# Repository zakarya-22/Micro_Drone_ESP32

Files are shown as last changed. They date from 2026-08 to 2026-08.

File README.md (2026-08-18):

# 🚁 DIY ESP32-C3 Micro-Drone

## 1. Introduction et Objectif du Projet
L'objectif de ce projet est la conception de A à Z d'un mini-drone quadricoptère basé sur le microcontrôleur ESP32-C3. Ce projet multidisciplinaire couvre le prototypage mécanique, la conception électronique et le développement logiciel embarqué. Il implique le contrôle PWM de 4 moteurs à courant continu via des MOSFETs, la lecture de capteurs d'attitude (IMU) via I2C, et la gestion d'une alimentation par batterie LiPo.

## 2. 🛠️ Architecture Matérielle (Hardware)

* **Microcontrôleur :** ESP32-C3 Super Mini (Wi-Fi/Bluetooth, monocœur RISC-V).
* **Actionneurs :** 4 x Moteurs à courant continu (Coreless) avec hélices profilées.
* **Électronique de puissance :** Transistors MOSFETs pour la commutation des moteurs.
* **Capteur :** IMU (Inertial Measurement Unit) communicant en I2C pour la lecture de l'assiette du drone.
* **Alimentation :** Batterie LiPo Tattu 300mAh (avec alimentation de laboratoire utilisée pour les phases de test).
* **Mécanique :** Châssis conçu sur-mesure via **FreeCAD** et imprimé en 3D.
* **Circuit imprimé :** Routage réalisé sur **KiCad** et usinage d'un PCB personnalisé à l'aide d'une fraiseuse LPKF.

## 3. 💻 Architecture Logicielle (Software)
* **Environnement de développement :** Arduino IDE.
* **Modularité :** Le code est actuellement développé en modules séparés pour isoler et valider chaque sous-système de manière unitaire :
  * Un module dédié à l'acquisition des données de l'IMU via le bus I2C.
  * Un module dédié à la génération des signaux PWM (via `ledcWrite`) pour le contrôle de la vitesse des moteurs.

## 4. 🐛 Historique de Débogage et Résolution des Problèmes

Au cours du développement, plusieurs défis techniques ont été rencontrés et résolus méthodiquement :

### Défi 1 : Blocage de l'ESP32-C3 au démarrage (Erreur ESP-ROM)
* **Symptôme :** Après le téléversement du code, la carte refusait de lancer le programme et affichait uniquement le message `ESP-ROM` sur le port série.
* **Diagnostic :** La broche GPIO 9 (broche de "Strapping" définissant le mode de démarrage) mesurait une tension flottante de 0.2V au lieu d'un état haut (3.3V), forçant l'entrée en mode flash (*Download Mode*).
* **Solution :** Un reset électrique complet (décharge des condensateurs en court-circuitant 3V3 et GND hors tension) a purgé les charges résiduelles, validant la nécessité d'états électriques stables sur les broches de strapping.

### Défi 2 : Redémarrages intempestifs en charge (Brownout detector was triggered)
* **Symptôme :** Dès l'activation des moteurs, l'ESP32 plantait avec l'erreur `Brownout`.
* **Diagnostic :** L'appel de courant brutal des moteurs faisait chuter la tension d'alimentation sous le seuil critique (environ 2.8V).
* **Solution temporaire :** Passage sur une alimentation de laboratoire (3.65V - 4A) pour garantir la puissance nécessaire.

### Défi 3 : Problème de poussée inversée (Le drone "frappe" le sol)
* **Symptôme :** Les moteurs tournaient, mais le flux d'air plaquait le drone au sol au lieu de le soulever.
* **Diagnostic :** Sens de rotation incorrect et profil aérodynamique des hélices non respecté. Les MOSFETs unidirectionnels ne permettent pas de changer le sens logiciellement.
* **Solution :** Retournement physique des hélices (face bombée vers le haut) et inversion du câblage matériel des moteurs sur le PCB.

### Défi 4 : Comportement aléatoire des moteurs au démarrage
* **Symptôme :** Activation erratique des moteurs lors de la mise sous tension.
* **Diagnostic :** Les grilles (Gates) des MOSFETs captaient des signaux parasites à cause de la haute impédance (état flottant) des GPIOs pendant la séquence de boot de l'ESP32.
* **Solution :** Ajout de résistances de pull-down (10kΩ) entre les grilles et la masse (GND) pour forcer l'état bas tant que le PWM n'est pas envoyé logiciellement.

### Défi 5 : Capteur IMU non détecté sur le bus I2C
* **Symptôme :** Échec du scanner I2C, chute de la tension 3.3V du capteur.
* **Diagnostic :** Court-circuit ou inversion de polarité (VCC / GND) mettant l'alimentation en sécurité et bloquant le bus.
* **Action :** Isolement immédiat du circuit et inspection du câblage pour prévenir la destruction des composants.

## 5. 🚧 Problèmes Actuels et Améliorations Matérielles

Actuellement, les sous-systèmes fonctionnent parfaitement de manière isolée. Cependant, lors de la combinaison des codes, le microcontrôleur n'arrive pas à gérer les moteurs de façon stable (perte de puissance ou redémarrage). Voici les deux pistes de résolutions matérielles prioritaires en cours :

1. **Le seuil de commutation des MOSFETs (Logic-Level) :** L'ESP32-C3 fonctionne en logique 3.3V. Si les MOSFETs utilisés nécessitent une tension de grille de 5V ou plus pour saturer complètement (s'ouvrir à 100%), ils fonctionnent en régime ohmique (comme une résistance). Ils brident alors le courant destiné aux moteurs et dissipent de la chaleur. L'amélioration consistera à s'assurer d'utiliser des MOSFETs "Logic-Level" (ex: SI2302) ayant une très faible tension de seuil de grille ($V_{GS(th)}$).
2. **Filtrage et découplage de puissance (Brownout matériel) :** Pour absorber le gigantesque pic de courant généré au démarrage par 4 moteurs *coreless* et protéger l'ESP32 des chutes de tension, l'ajout d'un condensateur de forte valeur (ex: 470µF) au plus près de la ligne d'alimentation générale, combiné à des condensateurs de découplage proches de l'ESP32, est nécessaire.

## 6. 🚀 État Actuel et Prochaines Étapes
- [x] Modélisation du châssis sur FreeCAD.
- [x] Routage et usinage du PCB sur KiCad/LPKF.
- [x] Validation unitaire du code de l'IMU.
- [x] Validation unitaire du code PWM pour les moteurs.
- [ ] Résolution du problème d'alimentation/contrôle moteur avec l'ESP32 (Code combiné).
- [ ] Fusion propre du code dans un `flight_controller` unifié.
- [ ] Remplacement de l'alimentation de labo par la batterie Tattu 300mAh.
- [ ] Implémentation et réglage de la boucle d'asservissement PID.

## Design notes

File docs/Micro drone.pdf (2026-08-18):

🚁 Liste du matériel : Le Micro-Drone (Cible : ~55g)
Pour le cerveau du drone, je te conseille de prendre une version "Mini" de l'ESP32 pour gratter de précieux grammes.
Composant | Spécificités exactes (Mots-clés AliExpress) | Poids approx. | Prix estimé (€)
Microcontrôleur | ESP32 D1 Mini mais après brûlure esp32 super mini | 5 g | 4.00
Capteur IMU | MPU6050 Module (Gyroscope 3 axes + Accéléromètre) | 2 g | À l’école
Capteur Altitude | VL53L0X Time of flight sensor (Capteur laser) | 1.5 g | 3.00
Moteurs (x4) | Brushed 716 | 20 g (5g x4) | 6.00
Hélices (x8) | 55mm Propellers for the motors | 2 g | 2.00
MOSFETs (x10) | AO3400 | < 1 g | À l’école
Diodes & Résis. | Diodes SS14 (SMD) + Résistances 10k Ohms SMD (0805 ou 1206) | < 1 g | À l’école

Batterie 1S | 3.7V 300mAh Tattu battery JST/PH2.0 | 15 g | 10.00 (lot)
Structure | Châssis imprimé en 3D à l’école | ~10 g | 0.00 (École)
TOTAL | Objectif : Vol dynamique et autonomie de 4-6 minutes | ~56.5 g | ~29.50 €

🎮 Liste du matériel : La Manette de contrôle (Télécommande)

Composant | Spécificités exactes (Mots-clés AliExpress) | Prix estimé (€)
Microcontrôleur | ESP32 NodeMCU 38 pins (Classique, facile à brancher) | 5.00
Joysticks (x2) | Dual Axis XY Joystick Module (KY-023) | 2.50

Pour la manette, le poids n'a pas d'importance. L'utilisation d'un second ESP32 est l'option la plus intelligente : cela te permet d'utiliser le protocole ESP-NOW (un protocole Wi-Fi direct créé par Espressif, ultra-rapide, sans routeur, avec une latence quasi nulle).

📅 Plan de travail et Méthodologie

Ce projet demande de la rigueur. Si tu assembles tout en espérant que ça vole du premier coup, tu risques de casser tes composants. Voici la marche à suivre par étapes :

Phase 1 : Électronique et Motorisation (Test sur table)

1. Soude un seul moteur avec son MOSFET, sa diode et sa résistance sur un petit bout de plaque d'essai.
2. Écris un code très simple sur l'ESP32 pour faire varier la vitesse de ce moteur (PWM) de 0 à 100%.
3. Objectif : Valider ton circuit de puissance avant de le multiplier par 4.

Phase 2 : Communication (ESP-NOW)

1. Câble tes joysticks sur l'ESP32 de la manette.
2. Écris le code pour lire les valeurs des joysticks et les envoyer via ESP-NOW à l'ESP32 du drone.
3. Fais afficher ces valeurs sur le moniteur série de l'ordinateur connecté au drone pour vérifier que la transmission est instantanée et sans perte.

Phase 3 : Lecture de l'IMU et Programmation du PID (Le cœur du projet)

1. Branche le MPU6050 sur le drone (bus I2C).
2. Applique un filtre (Filtre Complémentaire ou Madgwick) pour obtenir les angles d'inclinaison (Pitch, Roll, Yaw) propres, malgré les vibrations.
3. Implémente la boucle PID (Proportionnelle, Intégrale, Dérivée). C'est l'algorithme qui dit : "Si je penche à gauche, j'accélère les moteurs gauches pour revenir à plat".

Phase 4 : Tests en "Tethered" (Vol captif)

1. Imprime ton châssis 3D et assemble tout le drone.
2. Fixe le drone à un système de balancier (une tige traversant le drone) ou attache-le par le dessus avec un fil mou.
3. Règle les valeurs de ton PID jusqu'à ce que le drone se stabilise tout seul sans s'emballer.

4. Dernière étape : Intègre le capteur VL53L0X pour gérer le maintien de l'altitude.

📍 Phase 1 : L'Inventaire et le Schéma Électrique (Eeschema)

Le but : Dire à KiCad "qui est connecté à quoi" avec les vrais composants.

1. Placement des Symboles : Nous allons chercher et placer les symboles de l'ESP32, de l'IMU, des 4 MOSFETs (A3400), des 4 Diodes (1N5819), des 8 Résistances, des Condensateurs et de la prise Batterie.
2. Câblage Virtuel : Nous allons tracer les fils verts pour relier tout ce beau monde (création des "Nets").
3. Assignation des Empreintes (Footprints) : C'est l'étape cruciale. Nous allons lier chaque symbole à son empreinte physique réelle (SOT-23 pour le MOSFET, empreinte traversante pour vos diodes, etc.).

📍 Phase 2 : Le Dessin du Châssis (Edge.Cuts)

Le but : Définir la forme physique du drone et les trous pour les moteurs.

1. Export vers le PCB : Nous basculerons sur l'éditeur de circuit imprimé (Pcbnew).
2. La Géométrie : Sur la couche jaune Edge.Cuts, nous dessinerons la forme en "X".
3. Les Moteurs : Nous créerons les cercles parfaits aux extrémités pour encastrer vos moteurs brushed.

📍 Phase 3 : Le Placement Stratégique (Layout)

Le but : Poser les composants sur le châssis de manière équilibrée et logique.

1. Le Cœur : Placement de l'IMU aux coordonnées (0,0) (le centre de gravité absolu).
2. Le Cerveau : Placement de l'ESP32 au centre, en respectant l'antenne dans le vide.
3. Les Muscles : Placement des blocs de puissance (MOSFET + Diode + Résistance) au départ de chaque bras.
4. L'Énergie : Placement de la prise BT2.0 et de son gros condensateur de filtrage.

📍 Phase 4 : Le Routage et les Masses (Routing)

Le but : Relier physiquement les composants avec du cuivre.

1. Les Autoroutes de Puissance : Tracer des pistes très larges (1.5mm ou plus) pour la batterie et les moteurs.
2. Les Chemins de Signaux : Tracer des pistes fines pour le PWM des moteurs et la communication (I2C/SPI) de l'IMU.
3. Le Bouclier (Plans de Masse) : Remplir les zones vides de cuivre relié au GND, en n'oubliant surtout pas la règle d'or : pas de cuivre sous l'antenne de l'ESP32.
4. L'Inspection (DRC) : Lancer le vérificateur de KiCad pour s'assurer qu'il n'y a pas de court-circuit avant la fabrication.

📋 La Liste des Composants Corrigée (BOM)

### 1. Contrôleur & Capteurs (Le Cerveau)

- 1x Module ESP32 : (Votre modèle à 40 broches). Empreinte : Traversante personnalisée (grâce au fichier .kicad_mod lié).
- 1x Module IMU 9 axes : (Breakout board). Empreinte : Rangée de connecteurs femelles (Sockets).
- 1x Module Altimètre/Baromètre : (Ex: BMP280 ou MS5611). Utile pour stabiliser automatiquement l'altitude du drone. Empreinte : Rangée de connecteurs femelles (Sockets).

### 2. Circuit de Puissance (Moteurs ×4)

- 4x Transistors MOSFET AO3400 : Empreinte : CMS SOT-23 (minuscules, sans pattes).
- 4x Diodes de roue libre 1N5819 : Empreinte : Traversante DO-41 (gros cylindres avec vos longues pattes).
- 4x Résistances de Tirage (Pull-down) 10 kΩ : Empreinte : Traversante R_Axial (avec vos longues pattes).

### 3. Alimentation & Filtrage

- 1x Connecteur de Batterie BT2.0 : À souder au bout de deux fils ou directement sur le PCB. Empreinte : 2 pastilles traversantes larges (Pads).
- 1x Gros Condensateur Électrolytique (220µF à 470µF) : Le réservoir d'énergie. Empreinte : Traversante polarisée (CPol).
- 3x Petits Condensateurs Céramiques 100 nF : Vos condensateurs de filtrage à longues pattes (1 pour l'ESP32, 1 pour l'IMU, 1 pour l'altimètre). Empreinte : Traversante non polarisée (C_Disc).

### 4. Connexions & Divers

- 4x Paires de Pastilles moteurs : (2 pads par bras, pas de connecteurs physiques) pour souder vos moteurs en direct.
- 4x Pastilles de test (Test pads) : Petites zones de cuivre nu pour mesurer le GND, 3.3V, SDA et SCL.

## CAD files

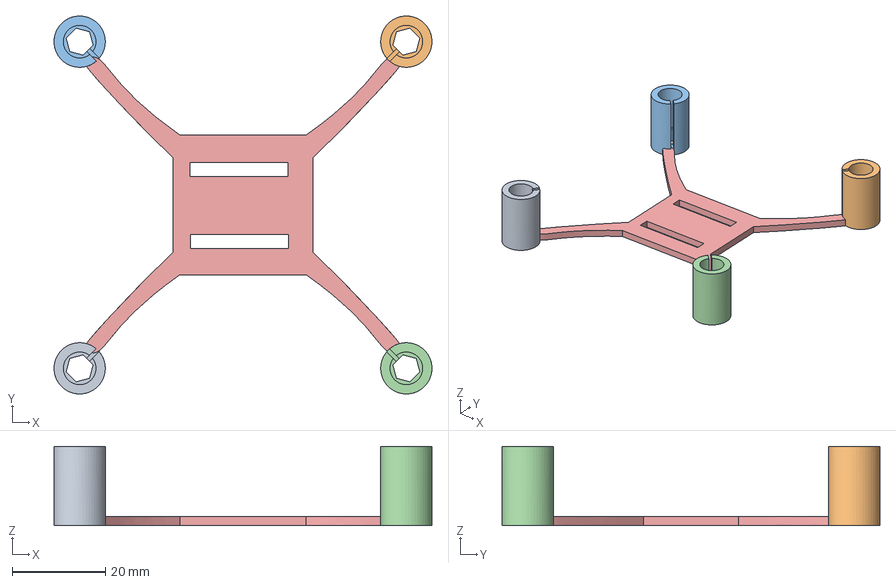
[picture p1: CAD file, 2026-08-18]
hardware/3D_Chassis/support drone.FCStd
81.0 x 81.0 x 17.0 mm

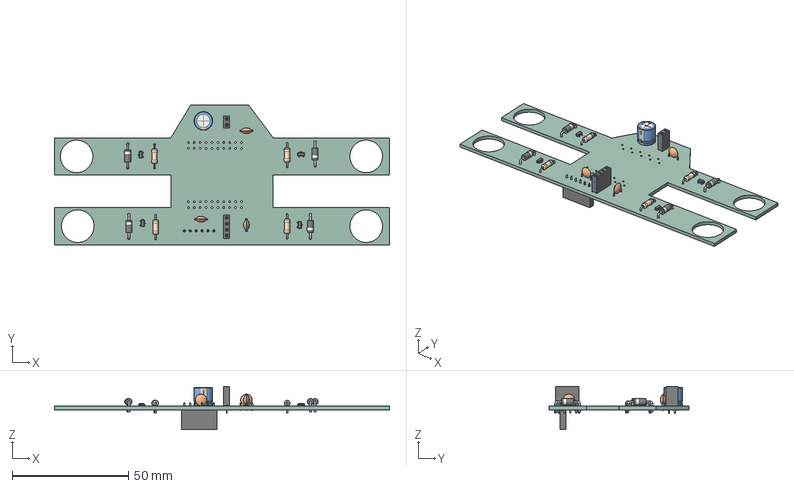
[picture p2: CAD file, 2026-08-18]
hardware/KiCad_PCB/Kicad_esp32_super_mini/pcb_v2.step
144.0 x 60.0 x 18.7 mm
D_DO-41_SOD81_P10.16mm_Horizontal x 4
R_Axial_DIN0207_L63mm_D25mm_P1016mm_Horizontal x 4
SOT-23 x 4
CP_Radial_D80mm_P350mm
C_Disc_D50mm_W25mm_P500mm x 3
PinSocket_1x04_P2.54mm_Vertical
PinSocket_1x02_P2.54mm_Vertical
PinSocket_1x06_P2.54mm_Vertical
Micro_drone_PCB
